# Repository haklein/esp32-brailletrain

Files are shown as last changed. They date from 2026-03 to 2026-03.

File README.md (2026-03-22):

# ESP32-S3 Braille Trainer

A braille training device that connects an ESP32-S3 to a HandyTech BrailleWave 40-cell display via MAX232 level shifter. Includes a web UI for settings and monitoring, BLE HID pass-through for screen reader use, and maintenance tools.

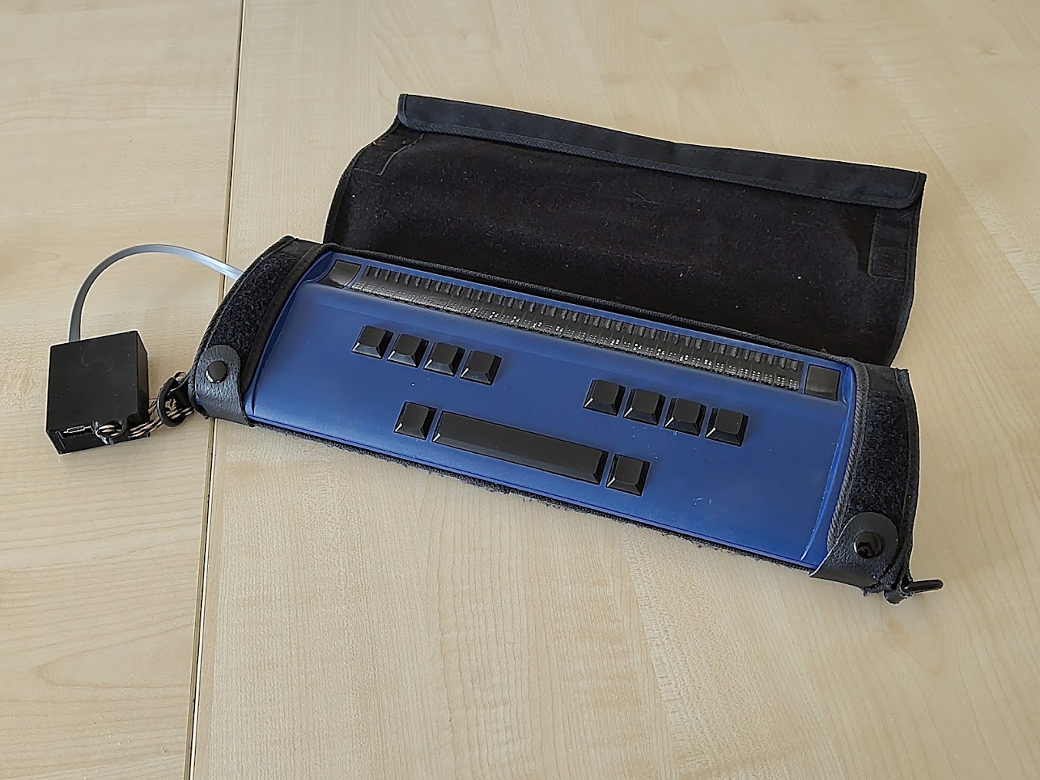
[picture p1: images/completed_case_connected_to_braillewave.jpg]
3D-printed adapter case with RJ-12 cable plugged into a blue HandyTech BrailleWave 40-cell braille display in its carry pouch


## Hardware

- Seeed Studio XIAO ESP32-S3 (or ESP32-S3-DevKitC-1)
- HandyTech BrailleWave (40 cells, HT serial protocol)
- MAX232 level shifter (TTL ↔ RS-232)
- 14500 Li-Ion battery (3.7V 1000mAh)

```
XIAO:      D1/A1 (GPIO2, TX) → MAX232 → RJ-12 → BrailleWave
           D2/A2 (GPIO3, RX) ← MAX232 ← RJ-12 ← BrailleWave

DevKitC-1: GPIO 7 (TX) → MAX232 → RJ-12 → BrailleWave
           GPIO 6 (RX) ← MAX232 ← RJ-12 ← BrailleWave
```

| | |
|---|---|
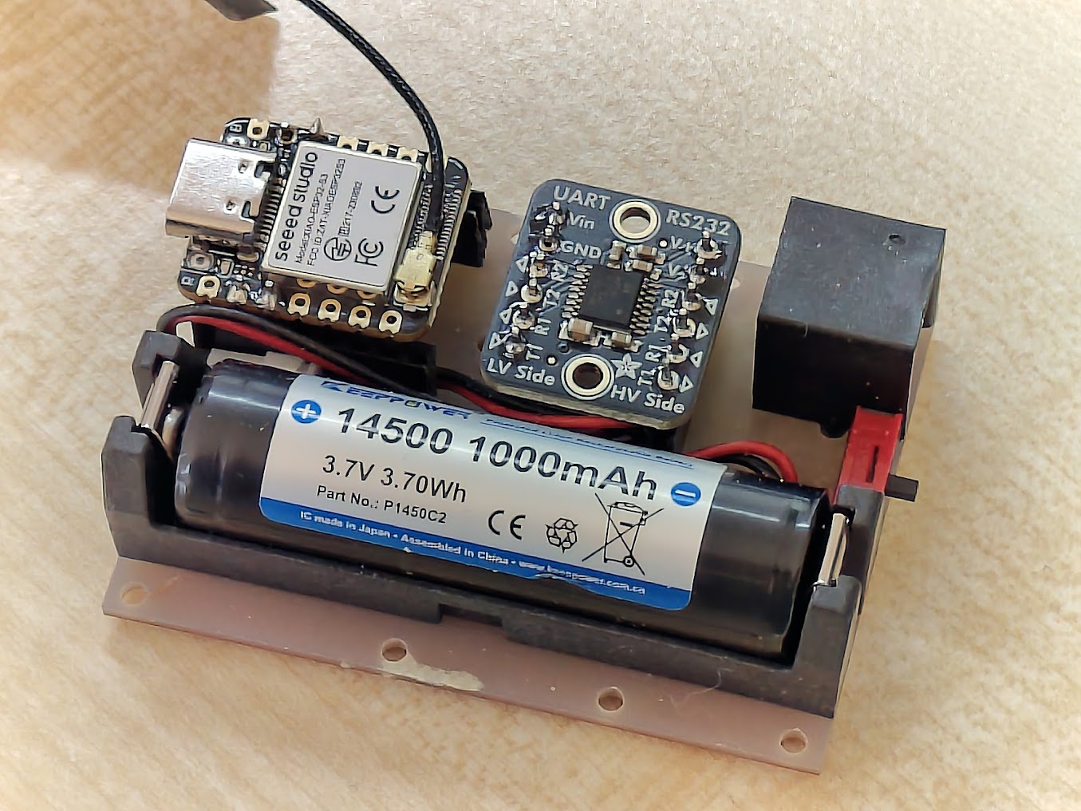
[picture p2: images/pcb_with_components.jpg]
Custom PCB with Seeed XIAO ESP32-S3 module, MAX232 level shifter, and 14500 Li-Ion battery in holder, viewed from above
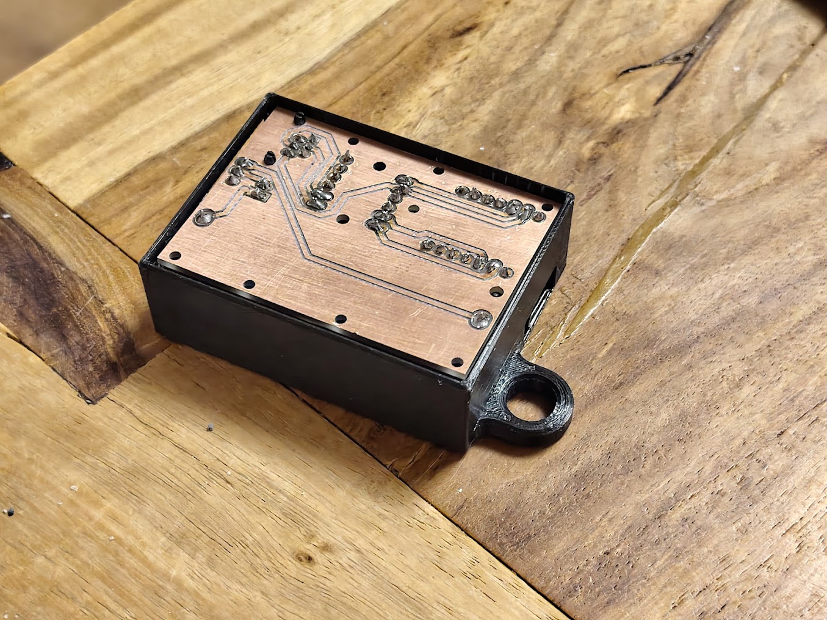
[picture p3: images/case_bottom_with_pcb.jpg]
Bottom of 3D-printed case showing milled copper PCB with through-hole solder joints and RJ-12 cable exit
|  |  |
| XIAO ESP32-S3, MAX232, 14500 battery holder | Custom PCB in 3D-printed case with RJ-12 connector |

### Bill of Materials

| Component | Description | Link |
|---|---|---|
| Seeed Studio XIAO ESP32-S3 | Microcontroller with WiFi + BLE | [Seeed Wiki](https://wiki.seeedstudio.com/xiao_esp32s3_getting_started/) |
| Adafruit RS232 Pal | MAX3232E dual-channel UART to RS-232 level shifter | [Adafruit 5987](https://www.adafruit.com/product/5987) |
| Keystone 1028 | 14500 / AA battery holder | |
| MSK12D18G2 | SPDT slide switch, 3-pin, 2.54mm pitch (or any compatible) | |
| RJ-12 socket | 6P6C through-hole, for direct connection to BrailleWave | |
| 14500 Li-Ion battery | 3.7V 1000mAh (AA-size lithium) | |

### Schematic

<a href="pcb/Schematic_esp32-brailletrain_2026-03-22.svg">Circuit schematic showing XIAO ESP32-S3 connected to MAX3232E level shifter, RJ-12 connector for BrailleWave, 14500 battery with slide switch, and status LED</a>

### PCB

Gerber files and a DXF for CNC milling are in the `pcb/` directory. The PCB was designed as a single-layer board, CNC milled with only the bottom side island-routed (see the included DXF).

**Note:** One screw hole collides with the 5V SMD pad on the XIAO ESP32-S3. This was not fixed since it doesn't matter for the milled version (no top copper). If you plan to send the Gerber to a PCB manufacturer, be aware of this overlap — you'll likely want to leave the top copper layer empty or remove that pad from the design.

## Features

### Training
- Letter, word, and mixed training modes
- 26-level progressive curriculum (teaching order: e, a, i, o, s, h, b, c, ...)
- Oxford 5000 word list with frequency weights, filtered by introduced letters
- Per-letter statistics, confusion tracking, streak counting
- Auto-advancement when accuracy thresholds are met
- Confusable pair drills (d/f, e/i, h/j, m/n, etc.) plus actual confusion-based selection
- Per-letter confusion tracking across both letter and word modes (e.g., bed→beg records d/g confusion)
- Mirror mode (right-hand) and wide word spacing options
- Ergonomic positioning: left word at cell 12, mirror at cell 24, 4-cell gap
- Configurable max word length
- All settings persisted across reboots

### Web UI

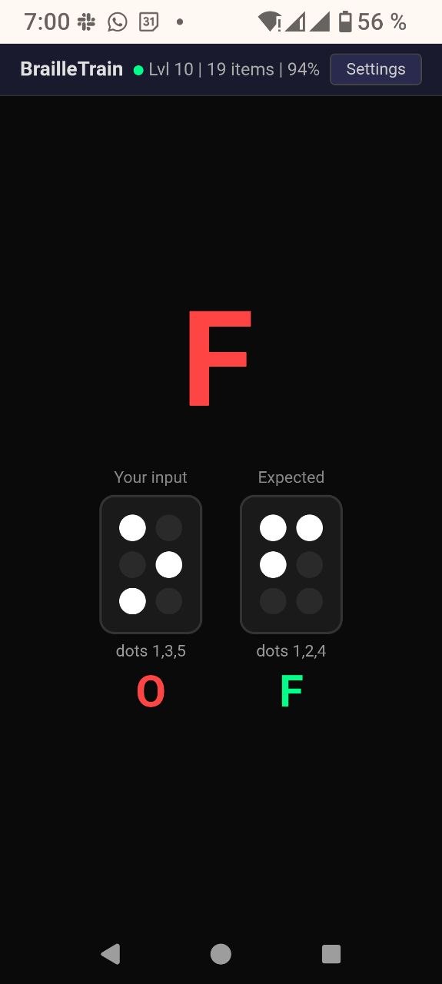
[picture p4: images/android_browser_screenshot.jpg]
Android browser showing BrailleTrain web UI after an incorrect answer: prompted letter F, user typed O, with dot pattern comparison showing dots 1,3,5 versus expected dots 1,2,4


- Real-time WebSocket updates at `http://brailletrain.local`
- Does not reveal the prompted letter/word — only shows result after input
- Level selector, mode switcher, option toggles
- Screen wake lock during training (releases after 5 min inactivity)
- Optional sound feedback: chime on correct, buzz on error (Web Audio API, no samples)
- Statistics panel: per-letter accuracy table, top confusion pairs, overall stats
- Reset option to clear all statistics and settings (e.g., for user change)
- BrailleWave connection status indicator with auto-reconnect

### WiFi
- Always runs AP mode (SSID: `BrailleTrain`, open)
- Optional STA mode — scan and connect to existing networks from the web UI
- Credentials saved to flash, auto-reconnects on boot
- mDNS: `http://brailletrain.local`

### BLE HID Braille Display (Dual Protocol)
- Advertises as "BrailleWave 40" (BLE HID, appearance 0x03C9)
- When a screen reader connects via BLE, the device enters pass-through mode
- Host cell data → ESP32 → UART → BrailleWave display
- BrailleWave keys → UART → ESP32 → HID input reports → Host
- Auto-reverts to trainer mode on BLE disconnect
- **Dual protocol support** — both served simultaneously on one BLE HID service:
  - **Standard HID Braille** (Usage Page 0x41, reports 0x11/0x12/0x13): for iOS VoiceOver, Android TalkBack, and other standard HID Braille consumers
  - **HandyTech USB-HID** (Vendor reports 0x01/0x02/0xFB/0xFC): serial tunnel for brltty's `ht` driver — wraps HT UART frames in HID reports
- PnP ID: HandyTech vendor 0x1FE4, product 0x0003 (USB-HID adapter)

#### brltty on Linux (Fedora/GNOME)

brltty's `ht` driver uses USB-specific HID APIs, so BLE HID requires a bridge.
`braille-bridge.py` translates between the ESP32's HT vendor HID reports and a
PTY that brltty reads as a serial device.

```bash
# Build the tcsetattr shim (one-time, needed because PTYs don't support parity)
gcc -shared -fPIC -o /tmp/pty_serial_shim.so - -ldl <<'EOF'
#define _GNU_SOURCE
#include <dlfcn.h>
#include <termios.h>
#include <unistd.h>
#include <errno.h>
typedef int (*fn)(int, int, const struct termios *);
int tcsetattr(int fd, int a, const struct termios *t) {
    static fn real = 0;
    if (!real) real = (fn)dlsym(RTLD_NEXT, "tcsetattr");
    int r = real(fd, a, t);
    if (r == -1 && errno == EINVAL && isatty(fd)) { errno = 0; return 0; }
    return r;
}
EOF

# Start bridge (auto-detects hidraw device)
sudo python3 braille-bridge.py &

# Start brltty
sudo LD_PRELOAD=/tmp/pty_serial_shim.so brltty -b ht -d /tmp/braillewave -n &

# Start Orca for GUI braille output
orca --replace &
```

### Status LED
- Flashes during BrailleWave connection attempts (yellow on DevKitC-1, white on XIAO)
- Solid on when connected (green on DevKitC-1, white on XIAO)
- Off when disconnected

### Maintenance
- **Exercise mode**: flips all dots on/off at slow (1s) or fast (200ms) intervals for 5 or 15 minutes — for pin break-in and cleaning
- **Test mode**: cycles through every dot on every cell sequentially; reports all key presses/releases in the web UI
- **Auto-reconnect**: detects BrailleWave sleep/power-off after 30s inactivity, reconnects within 3s of power-on (uses HT ping when supported, falls back to reset)
- Manual reconnect button
- **Device probe**: queries serial number, firmware version, cell count, RTC, firmness, ping support via HT extended protocol
- **RTC sync**: synchronize BrailleWave clock from ESP32 (requires NTP via WiFi STA)
- **Firmness control**: adjust pin pressure (soft/medium/hard) on supported models

## Building

Requires [PlatformIO](https://platformio.org/).

```bash
pio run              # build
pio run -t upload    # flash
```

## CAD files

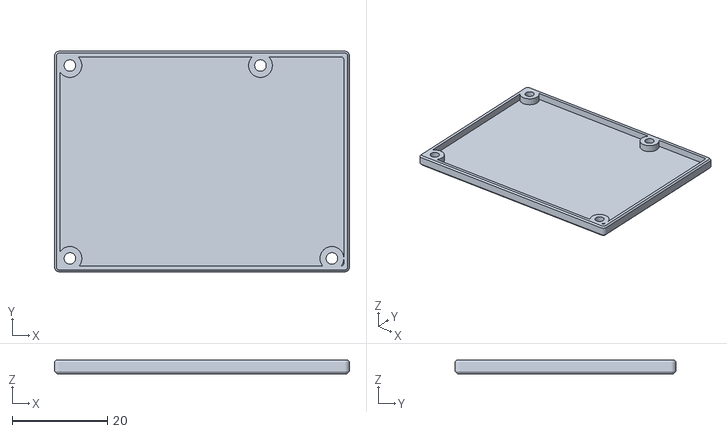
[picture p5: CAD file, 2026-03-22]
cad/brailletrain-case-lid.stl
61.9 x 46.3 x 3.00

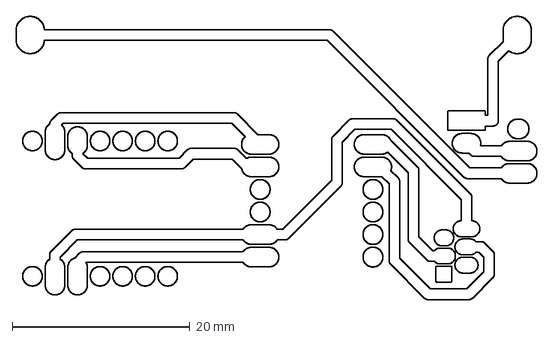
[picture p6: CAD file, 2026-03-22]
pcb/Gerber_BottomLayer.GBL_iso.DXF
58.7 x 31.9 mm

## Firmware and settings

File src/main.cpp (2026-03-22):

/*
 * ESP32-S3 Braille Trainer with web UI
 *
 * Hardware:
 *   BRL_TX -> MAX232 RX pin -> DB9 -> BrailleWave
 *   BRL_RX <- MAX232 TX pin <- DB9 <- BrailleWave
 *   USB CDC -> PC serial monitor at 115200
 *   Pin assignments per board in platformio.ini
 *
 * WiFi AP "BrailleTrain" -> http://192.168.4.1
 */

#include <Arduino.h>
#include <WiFi.h>
#include <ESPmDNS.h>
#include <ArduinoOTA.h>
#include <LittleFS.h>
#include <ESPAsyncWebServer.h>
#include <ArduinoJson.h>

#include "braille_data.h"
#include "progress.h"
#include "engine.h"
#include "wordlist.h"
#include "html_content.h"
#include "ble_braille.h"

// =========================================================================
// Hardware
// =========================================================================

#define DBG Serial  // USB CDC on ESP32-S3

// BRL_TX and BRL_RX defined via build flags in platformio.ini
HardwareSerial BRL(1);

// Status LED (optional, per-board via platformio.ini)
//   LED_PIN  = simple GPIO LED (active low, XIAO)
//   LED_RGB  = addressable WS2812 (DevKitC-1, GPIO48)
#if defined(LED_RGB)
static inline void led_on()      { neopixelWrite(LED_RGB, 0, 20, 0); }  // green
static inline void led_attempt() { neopixelWrite(LED_RGB, 20, 12, 0); } // yellow
static inline void led_off()     { neopixelWrite(LED_RGB, 0, 0, 0); }
#elif defined(LED_PIN)
static inline void led_on()      { digitalWrite(LED_PIN, LOW); }  // active low
static inline void led_attempt() { digitalWrite(LED_PIN, LOW); }
static inline void led_off()     { digitalWrite(LED_PIN, HIGH); }
#else
static inline void led_on()      {}
static inline void led_attempt() {}
static inline void led_off()     {}
#endif

#define HT_PKT_RESET    0xFF
#define HT_PKT_OK       0xFE
#define HT_PKT_BRAILLE  0x01
#define HT_PKT_EXTENDED 0x79
#define HT_MODEL_WAVE   0x05
#define HT_SYN          0x16

// Extended packet types
#define HT_EXT_BRAILLE          0x01
#define HT_EXT_KEY              0x04
#define HT_EXT_CONFIRMATION     0x07
#define HT_EXT_PING             0x19
#define HT_EXT_GET_SERIAL       0x41
#define HT_EXT_SET_RTC          0x44
#define HT_EXT_GET_RTC          0x45
#define HT_EXT_SET_FIRMNESS     0x60
#define HT_EXT_GET_FIRMNESS     0x61
#define HT_EXT_GET_PROTO_PROPS  0xC1
#define HT_EXT_GET_FW_VERSION   0xC2

// =========================================================================
// Web server
// =========================================================================

AsyncWebServer server(80);
AsyncWebSocket ws("/ws");

// =========================================================================
// Settings (changed via web or defaults)
// =========================================================================

static volatile bool mirror_enabled = false;
static volatile bool word_spacing = false;
static volatile bool keepalive_enabled = true;
static volatile bool ergonomic_enabled = false;
static volatile int max_word_len = 0;  // 0 = unlimited

enum TrainMode { MODE_LETTERS, MODE_WORDS, MODE_MIXED };
static volatile int training_mode = MODE_LETTERS;

// BrailleWave connectivity
static bool brl_connected = false;
static unsigned long last_key_time = 0;
static unsigned long last_keepalive = 0;
static volatile bool pending_reconnect = false;

// Pending settings from WebSocket (processed in main loop)
static volatile int pending_level = -1;

// Pending WiFi commands from WebSocket
static volatile bool pending_wifi_scan = false;
static volatile bool pending_wifi_connect = false;
static volatile bool pending_wifi_disconnect = false;
static char pending_ssid[33] = {0};
static char pending_pass[65] = {0};

// =========================================================================
// Key codes
// =========================================================================

struct KeyInfo { uint8_t code; int dot; };

static const KeyInfo KEY_TABLE[] = {
    {0x03, 7}, {0x07, 3}, {0x0B, 2}, {0x0F, 1},
    {0x13, 4}, {0x17, 5}, {0x1B, 6}, {0x1F, 8},
    {0x10, -1},  // space
    {0x0C, -2},  // nav left
    {0x14, -3},  // nav right
    {0x08, -4},  // nav prev
    {0x04, -5},  // nav next
};
#define KEY_TABLE_SIZE (sizeof(KEY_TABLE) / sizeof(KEY_TABLE[0]))

#define DOT_KEY(ki)  ((ki).dot > 0)
#define NAV_LEFT   0x0C
#define NAV_RIGHT  0x14
#define NAV_PREV   0x08
#define NAV_NEXT   0x04
#define KEY_SPACE  0x10

// =========================================================================
// HT protocol
// =========================================================================

static bool ht_reset() {
    DBG.println("HT reset...");
    led_attempt();
    while (BRL.available()) BRL.read();
    BRL.write((uint8_t)HT_PKT_RESET);
    BRL.flush();
    delay(300);

    uint8_t buf[16];
    int count = 0;
    unsigned long deadline = millis() + 1000;
    while (millis() < deadline && count < 16)
        if (BRL.available()) buf[count++] = BRL.read();

    for (int i = 0; i < count; i++)
        if (buf[i] == HT_PKT_OK) {
            DBG.println("  BrailleWave OK");
            led_on();  // stay solid
            return true;
        }
    led_off();
    return false;
}

static void ht_write_cells(const uint8_t *cells) {
    BRL.write((uint8_t)HT_PKT_BRAILLE);
    BRL.write(cells, HT_CELLS);
    BRL.flush();
    delay(50);
    while (BRL.available()) BRL.read();
}

static void ht_clear() {
    uint8_t cells[HT_CELLS] = {0};
    ht_write_cells(cells);
}

// Send an extended packet: type + optional data
static void ht_send_ext(uint8_t type, const uint8_t *data = nullptr, int data_len = 0) {
    BRL.write((uint8_t)HT_PKT_EXTENDED);
    BRL.write((uint8_t)HT_MODEL_WAVE);
    BRL.write((uint8_t)(data_len + 1));  // length includes type byte
    BRL.write(type);
    if (data && data_len > 0) BRL.write(data, data_len);
    BRL.write((uint8_t)HT_SYN);
    BRL.flush();
}

// Read an extended packet response. Returns payload length (0 = no response).
// out_type gets the response type, out_data gets payload (up to out_max bytes).
static int ht_recv_ext(uint8_t *out_type, uint8_t *out_data, int out_max,
                       int timeout_ms = 500) {
    unsigned long deadline = millis() + timeout_ms;
    // Look for 0x79 header
    while (millis() < deadline) {
        if (!BRL.available()) { delay(1); continue; }
        int b = BRL.read();
        if (b != HT_PKT_EXTENDED) continue;

        // Read model, length, type
        while (BRL.available() < 3 && millis() < deadline) delay(1);
        if (BRL.available() < 3) return 0;
        uint8_t model = BRL.read();
        uint8_t len = BRL.read();     // includes type byte
        *out_type = BRL.read();
        int payload_len = len - 1;

        // Read payload + SYN
        int got = 0;
        while (got < payload_len && millis() < deadline) {
            if (BRL.available()) {
                uint8_t c = BRL.read();
                if (got < out_max) out_data[got] = c;
                got++;
            } else delay(1);
        }
        // Read trailing SYN
        while (millis() < deadline) {
            if (BRL.available()) { BRL.read(); break; }
            delay(1);
        }
        return min(got, out_max);
    }
    return 0;
}

// Ping — less disruptive than full reset for keepalive
static bool ht_ping() {
    while (BRL.available()) BRL.read();
    ht_send_ext(HT_EXT_PING);
    // Accept any response (extended confirmation, or even just bytes back)
    unsigned long deadline = millis() + 300;
    while (millis() < deadline) {
        if (BRL.available()) {
            while (BRL.available()) BRL.read();
            return true;
        }
        delay(5);
    }
    return false;
}

// Probe device: try all extended queries, return results as JSON
static void ht_probe(String &out) {
    JsonDocument doc;
    doc["t"] = "devinfo";
    uint8_t rtype, rbuf[64];
    int rlen;

    // Serial number
    while (BRL.available()) BRL.read();
    ht_send_ext(HT_EXT_GET_SERIAL);
    rlen = ht_recv_ext(&rtype, rbuf, sizeof(rbuf));
    if (rlen > 0) {
        rbuf[min(rlen, 63)] = 0;
        doc["serial"] = (const char *)rbuf;
        DBG.printf("HT serial: %s\n", rbuf);
    }

    // Firmware version
    while (BRL.available()) BRL.read();
    ht_send_ext(HT_EXT_GET_FW_VERSION);
    rlen = ht_recv_ext(&rtype, rbuf, sizeof(rbuf));
    if (rlen > 0) {
        rbuf[min(rlen, 63)] = 0;
        doc["firmware"] = (const char *)rbuf;
        DBG.printf("HT firmware: %s\n", rbuf);
    }

    // Protocol properties (cell count)
    while (BRL.available()) BRL.read();
    ht_send_ext(HT_EXT_GET_PROTO_PROPS);
    rlen = ht_recv_ext(&rtype, rbuf, sizeof(rbuf));
    if (rlen > 0) {
        doc["cells"] = (int)rbuf[0];
        DBG.printf("HT cells: %d\n", rbuf[0]);
    }

    // Firmness
    while (BRL.available()) BRL.read();
    ht_send_ext(HT_EXT_GET_FIRMNESS);
    rlen = ht_recv_ext(&rtype, rbuf, sizeof(rbuf));
    if (rlen > 0) {
        doc["firmness"] = (int)rbuf[0];
        doc["has_firmness"] = true;
        DBG.printf("HT firmness: %d\n", rbuf[0]);
    }

    // RTC
    while (BRL.available()) BRL.read();
    ht_send_ext(HT_EXT_GET_RTC);
    rlen = ht_recv_ext(&rtype, rbuf, sizeof(rbuf));
    if (rlen >= 7) {
        int year = (rbuf[0] << 8) | rbuf[1];
        char ts[32];
        snprintf(ts, sizeof(ts), "%04d-%02d-%02d %02d:%02d:%02d",
                 year, rbuf[2], rbuf[3], rbuf[4], rbuf[5], rbuf[6]);
        doc["rtc"] = ts;
        doc["has_rtc"] = true;
        DBG.printf("HT RTC: %s\n", ts);
    }

    // Ping
    bool ping_ok = ht_ping();
    doc["ping"] = ping_ok;

    serializeJson(doc, out);
}

// =========================================================================
// Display helpers (mirror + spacing)
// =========================================================================

static void display_cells(const uint8_t *src, int src_len) {
    uint8_t cells[HT_CELLS] = {0};

    int left = ergonomic_enabled ? 12 : 0;

    if (mirror_enabled) {
        // Right (mirror) copy: prefer cell 24, push left only if it won't fit
        int right = 24;
        if (right + src_len > HT_CELLS)
            right = HT_CELLS - src_len;
        if (right < 0) right = 0;

        // Left copy: push left if 4-cell gap can't be maintained
        if (left + src_len + 4 > right)
            left = right - src_len - 4;
        if (left < 0) left = 0;

        for (int i = 0; i < src_len && right + i < HT_CELLS; i++)
            cells[right + i] = src[i];
    } else {
        // No mirror: ensure it fits
        if (left + src_len > HT_CELLS)
            left = HT_CELLS - src_len;
        if (left < 0) left = 0;
    }

    for (int i = 0; i < src_len && left + i < HT_CELLS; i++)
        cells[left + i] = src[i];

    ht_write_cells(cells);
}

static void display_letter(char letter) {
    uint8_t c[1] = { char_to_cell(letter) };
    display_cells(c, 1);
}

static int word_to_cells(const char *word, uint8_t *out, int max_cells) {
    int pos = 0;
    for (int i = 0; word[i] && pos < max_cells; i++) {
        if (i > 0 && word_spacing) {
            if (pos < max_cells) out[pos++] = 0x00;
        }
        if (pos < max_cells) out[pos++] = char_to_cell(word[i]);
    }
    return pos;
}

static void display_word(const char *word) {
    uint8_t cells[HT_CELLS] = {0};
    int n = word_to_cells(word, cells, mirror_enabled ? HT_CELLS / 2 : HT_CELLS);
    display_cells(cells, n);
}

static void display_comparison(uint8_t got_cell, uint8_t exp_cell) {
    uint8_t cells[4] = { got_cell, 0, exp_cell, 0 };
    display_cells(cells, 4);
}

static void display_word_progress(const char *typed, int typed_len) {
    uint8_t cells[HT_CELLS] = {0};
    int pos = 0;
    for (int i = 0; i < typed_len; i++) {
        if (i > 0 && word_spacing) {
            if (pos < HT_CELLS) cells[pos++] = 0x00;
        }
        if (pos < HT_CELLS) cells[pos++] = char_to_cell(typed[i]);
    }
    display_cells(cells, pos);
}

// =========================================================================
// Chord accumulator
// =========================================================================

static uint8_t pressed_keys[16];
static int pressed_n = 0;
static uint8_t chord_keys[16];
static int chord_n = 0;

static bool chord_ready = false;
static uint8_t chord_dots = 0;
static bool chord_is_space = false;
static uint8_t chord_nav = 0;
static int routing_key = -1;

static const KeyInfo *lookup_key(uint8_t code) {
    for (int i = 0; i < (int)KEY_TABLE_SIZE; i++)
        if (KEY_TABLE[i].code == code) return &KEY_TABLE[i];
    return NULL;
}

static void finish_chord() {
    if (chord_n == 0) return;
    chord_dots = 0;
    chord_is_space = false;
    chord_nav = 0;

    for (int i = 0; i < chord_n; i++) {
        const KeyInfo *ki = lookup_key(chord_keys[i]);
        if (ki) {
            if (ki->dot > 0) chord_dots |= (1 << (ki->dot - 1));
            else if (chord_keys[i] == KEY_SPACE) chord_is_space = true;
            else chord_nav = chord_keys[i];
        }
    }
    chord_ready = true;
    chord_n = 0;
}

static void drain_ext_packet() {
    // Consume model + len, then len bytes + trailing SYN
    unsigned long deadline = millis() + 100;
    while (BRL.available() < 2 && millis() < deadline) delay(1);
    if (BRL.available() < 2) return;
    BRL.read();                         // model
    uint8_t len = BRL.read();           // length (includes type)
    int remain = len + 1;               // data + SYN
    while (remain > 0 && millis() < deadline) {
        if (BRL.available()) { BRL.read(); remain--; }
        else delay(1);
    }
}
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
void loop() {
    ArduinoOTA.handle();

    // BLE HID mode switching
    if (bleHID.connected() && app_mode == AppMode::TRAINER) {
        app_mode = AppMode::PASSTHROUGH;
        DBG.println("\n=== BLE host connected — pass-through mode ===");
        chord_reset();
        passthrough_reset_keys();
        ws_send("{\"t\":\"ble\",\"s\":\"connected\"}");
    } else if (!bleHID.connected() && app_mode == AppMode::PASSTHROUGH) {
        app_mode = AppMode::TRAINER;
        DBG.println("\n=== BLE host disconnected — trainer mode ===");
        state = State::RESET;
        ws_send("{\"t\":\"ble\",\"s\":\"disconnected\"}");
    }


    // Periodic WebSocket cleanup + heartbeat
    ws.cleanupClients();
    {
        static unsigned long last_hb = 0;
        if (millis() - last_hb > 5000) {
            last_hb = millis();
            ws_send("{\"t\":\"hb\"}");
        }
    }

    // Process pending WiFi commands
    if (pending_wifi_scan) {
        pending_wifi_scan = false;
        int n = WiFi.scanNetworks();
        JsonDocument doc;
        doc["t"] = "wscanr";
        JsonArray nets = doc["nets"].to<JsonArray>();
        for (int i = 0; i < n && i < 20; i++) {
            JsonObject net = nets.add<JsonObject>();
            net["s"] = WiFi.SSID(i);
            net["r"] = WiFi.RSSI(i);
            net["e"] = WiFi.encryptionType(i) != WIFI_AUTH_OPEN;
        }
        String out;
        serializeJson(doc, out);
        ws_send(out.c_str());
        WiFi.scanDelete();
    }

    if (pending_wifi_connect) {
        pending_wifi_connect = false;
        strlcpy(wifi_ssid, pending_ssid, sizeof(wifi_ssid));
        strlcpy(wifi_pass, pending_pass, sizeof(wifi_pass));
        wifi_save_creds();
        WiFi.disconnect(false);
        delay(100);
        WiFi.begin(wifi_ssid, wifi_pass);
        unsigned long t0 = millis();
        while (WiFi.status() != WL_CONNECTED && millis() - t0 < 10000)
            delay(100);
        if (WiFi.status() == WL_CONNECTED) {
            DBG.printf("WiFi STA: %s  IP: %s\n", wifi_ssid,
                       WiFi.localIP().toString().c_str());
            wifi_freeze_dhcp();
        } else
            DBG.printf("WiFi STA: %s failed\n", wifi_ssid);
        ws_notify_wifi_status();
    }

    if (pending_wifi_disconnect) {
        pending_wifi_disconnect = false;
        WiFi.disconnect(false);
        wifi_ssid[0] = 0;
        wifi_pass[0] = 0;
        wifi_save_creds();
        DBG.println("WiFi STA disconnected");
        ws_notify_wifi_status();
    }

    // Manual reconnect request
    if (pending_reconnect) {
        pending_reconnect = false;
        DBG.println("Reconnect requested");
        if (ht_reset()) {
            delay(500);
            while (BRL.available()) BRL.read();
            brl_connected = true;
            last_key_time = millis();
            chord_reset();
            state = State::SHOW_ITEM;
            if (app_mode != AppMode::TRAINER) app_mode = AppMode::TRAINER;
            ws_send("{\"t\":\"brl\",\"s\":true}");
            DBG.println("BrailleWave reconnected");
        } else {
            brl_connected = false;
            ws_send("{\"t\":\"brl\",\"s\":false}");
            DBG.println("BrailleWave not responding");
        }
    }

    // Background keepalive: ping BrailleWave after inactivity
    if (keepalive_enabled && app_mode == AppMode::TRAINER
        && state != State::RESET) {
        unsigned long now = millis();
        if (brl_connected) {
            // Check if still alive after 30s of no keys
            if (now - last_key_time > 30000 && now - last_keepalive > 10000) {
                last_keepalive = now;
                if (!ht_reset()) {
                    brl_connected = false;
                    led_off();
                    ws_send("{\"t\":\"brl\",\"s\":false}");
                    DBG.println("BrailleWave: lost connection");
                } else {
                    // Still connected, redisplay current item
                    if (state == State::WAIT_INPUT) {
                        if (item_is_word) display_word(current_item);
                        else display_letter(current_item[0]);
                    }
                }
            }
        } else {
            // Disconnected — try reconnect every 3 seconds
            if (now - last_keepalive > 3000) {
                last_keepalive = now;
                if (ht_reset()) {
                    delay(500);
                    while (BRL.available()) BRL.read();
                    brl_connected = true;
                    last_key_time = millis();
                    chord_reset();
                    state = State::SHOW_ITEM;
                    ws_send("{\"t\":\"brl\",\"s\":true}");
                    DBG.println("BrailleWave: reconnected");
                }
            }
        }
    }

    // Always process HT USB-HID reports (brltty may send via report 0x02
    // even when we're not in passthrough mode)
    if (bleHID.connected()) {
        // Forward HT serial data from brltty → UART
        uint8_t ht_data[HT_HID_DATA_SIZE];
        uint8_t ht_len = 0;
        if (bleHID.processHtData(ht_data, &ht_len)) {
            BRL.write(ht_data, ht_len);
            BRL.flush();
            DBG.printf("HT-HID: forwarded %d bytes to UART\n", ht_len);
        }
        // Forward HT firmware commands
        uint8_t cmd = 0;
        if (bleHID.processHtCommand(&cmd)) {
            if (cmd == 0x01) {
                ht_uart_rx_len = 0;
                while (BRL.available()) BRL.read();
                DBG.println("HT-HID: flush buffers");
            }
        }
        // Buffer any UART responses for brltty GET_REPORT(0x01)
        // (only when NOT in full passthrough, which handles this itself)
        if (app_mode != AppMode::PASSTHROUGH) {
            bool got_data = false;
            while (BRL.available()) {
                bleHID.htBufferUartByte(BRL.read());
                got_data = true;
            }
            if (got_data)
                bleHID.htNotifyData();
        }
    }

    switch (app_mode) {
    case AppMode::PASSTHROUGH: passthrough_loop(); break;
    case AppMode::EXERCISE:    exercise_loop(); break;
    case AppMode::TESTMODE:    testmode_loop(); break;
    default:                   trainer_loop(); break;
    }
}

// =========================================================================
// Pass-through mode: bridge BLE HID ↔ BrailleWave UART
// =========================================================================

static void passthrough_loop() {
    uint8_t cells[HT_CELLS];
    if (bleHID.processPendingCells(cells))
        ht_write_cells(cells);
    passthrough_poll(bleHID);
}


// =========================================================================
// Exercise mode: flip all dots on/off for pin break-in / cleaning
// =========================================================================

static void exercise_loop() {
    unsigned long now = millis();
    if (now >= exercise_end) {
        ht_clear();
        app_mode = AppMode::TRAINER;
        state = State::RESET;
        ws_send("{\"t\":\"exdone\"}");
        DBG.println("Exercise done");
        return;
    }

    if (now - exercise_toggle >= exercise_interval) {
        exercise_toggle = now;
        exercise_on = !exercise_on;
        uint8_t cells[HT_CELLS];
        memset(cells, exercise_on ? 0xFF : 0x00, HT_CELLS);
        ht_write_cells(cells);

        // Report remaining time
        int secs_left = (exercise_end - now) / 1000;
        char buf[64];
        snprintf(buf, sizeof(buf), "{\"t\":\"extick\",\"s\":%d}", secs_left);
        ws_send(buf);
    }
}

// =========================================================================
// Test mode: cycle dots sequentially + report key presses
// =========================================================================
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

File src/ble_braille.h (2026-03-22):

/*
 * BLE HID Braille Display — dual-protocol bridge to HandyTech BrailleWave.
 *
 * Exposes TWO protocols on a single BLE HID service:
 *
 * 1) Standard HID Braille Display (Usage Page 0x41, reports 0x11-0x13)
 *    For iOS VoiceOver, Android TalkBack, and other standard consumers.
 *
 * 2) HandyTech USB-HID serial tunnel (reports 0x01, 0x02, 0xFB, 0xFC)
 *    For brltty's 'ht' driver. Wraps HT serial frames in HID reports.
 *
 * When a BLE host connects, the ESP32 bridges both simultaneously:
 *   Host cell data  → UART → BrailleWave
 *   BrailleWave keys → UART → Host HID input reports
 */
#pragma once

#include <BLEDevice.h>
#include <BLEServer.h>
#include <BLEHIDDevice.h>
#include <BLE2902.h>
#include "braille_data.h"

// ---------------------------------------------------------------------------
// Report IDs
// ---------------------------------------------------------------------------

// Standard HID Braille Display (Usage Page 0x41)
#define RPT_STD_KEYS     0x11   // Input:  2B dot/nav key bits
#define RPT_STD_ROUTER   0x12   // Input:  5B routing key bits
#define RPT_STD_CELLS    0x13   // Output: 40B cell data

// HandyTech USB-HID serial tunnel (for brltty ht driver)
#define RPT_HT_OUT_DATA  0x01   // Input (GET_REPORT): HT serial from device
#define RPT_HT_IN_DATA   0x02   // Output (SET_REPORT): HT serial to device
#define RPT_HT_IN_CMD    0xFB   // Output (SET_REPORT): firmware command
#define RPT_HT_OUT_VER   0xFC   // Input (GET_REPORT): firmware version

// HT USB-HID data report payload size (matches real HT USB-HID adapters)
// Format: [report_id] [length] [data...] padded to fixed size
#define HT_HID_DATA_SIZE 64

// ---------------------------------------------------------------------------
// HID Report Descriptor — dual protocol
// ---------------------------------------------------------------------------
//
// Collection 1: Standard HID Braille (Usage Page 0x41)
//   Input Report 0x11 (2 bytes): dot keys 1-8, space, nav buttons
//   Input Report 0x12 (5 bytes): 40 router keys (1 bit each)
//   Output Report 0x13 (40 bytes): braille cell data from host
//
// Collection 2: HandyTech USB-HID serial tunnel (Usage Page 0x01 Generic)
//   Input Report 0x01 (64 bytes): HT serial data from device
//   Output Report 0x02 (64 bytes): HT serial data to device
//   Output Report 0xFB (2 bytes): firmware command
//   Input Report 0xFC (3 bytes): firmware version

static const uint8_t BRL_REPORT_MAP[] = {
    // =================================================================
    // Collection 1: Standard HID Braille Display
    // =================================================================
    0x05, 0x41,             // Usage Page (Braille Display)
    0x09, 0x01,             // Usage (Braille Display)
    0xA1, 0x01,             // Collection (Application)

    // --- Input Report 0x11: braille keyboard + nav ---
    0x85, RPT_STD_KEYS,     //   Report ID (0x11)
    0x05, 0x41,             //   Usage Page (Braille Display)
    // Dots 1-8
    0x0A, 0x01, 0x02,       //   Usage (Braille Keyboard Dot 1)
    0x0A, 0x02, 0x02,       //   Usage (Braille Keyboard Dot 2)
    0x0A, 0x03, 0x02,       //   Usage (Braille Keyboard Dot 3)
    0x0A, 0x04, 0x02,       //   Usage (Braille Keyboard Dot 4)
    0x0A, 0x05, 0x02,       //   Usage (Braille Keyboard Dot 5)
    0x0A, 0x06, 0x02,       //   Usage (Braille Keyboard Dot 6)
    0x0A, 0x07, 0x02,       //   Usage (Braille Keyboard Dot 7)
    0x0A, 0x08, 0x02,       //   Usage (Braille Keyboard Dot 8)
    0x15, 0x00,             //   Logical Minimum (0)
    0x25, 0x01,             //   Logical Maximum (1)
    0x75, 0x01,             //   Report Size (1)
    0x95, 0x08,             //   Report Count (8)
    0x81, 0x02,             //   Input (Data, Var, Abs)
    // Space + nav (5 buttons) + 3 padding bits
    0x0A, 0x09, 0x02,       //   Usage (Braille Keyboard Space)
    0x0A, 0x0A, 0x02,       //   Usage (Braille Keyboard Left Space)
    0x0A, 0x0B, 0x02,       //   Usage (Braille Keyboard Right Space)
    0x0A, 0x13, 0x02,       //   Usage (Joystick Left)
    0x0A, 0x14, 0x02,       //   Usage (Joystick Right)
    0x95, 0x05,             //   Report Count (5)
    0x81, 0x02,             //   Input (Data, Var, Abs)
    // 3-bit padding
    0x95, 0x03,             //   Report Count (3)
    0x81, 0x03,             //   Input (Const)

    // --- Input Report 0x12: router keys ---
    0x85, RPT_STD_ROUTER,   //   Report ID (0x12)
    0x05, 0x41,             //   Usage Page (Braille Display)
    0x09, 0xFA,             //   Usage (Router Set 1)
    0xA1, 0x02,             //   Collection (Logical)
    0x0A, 0x00, 0x01,       //     Usage (Router Key)
    0x15, 0x00,             //     Logical Minimum (0)
    0x25, 0x01,             //     Logical Maximum (1)
    0x75, 0x01,             //     Report Size (1)
    0x95, 0x28,             //     Report Count (40)
    0x81, 0x02,             //     Input (Data, Var, Abs)
    0xC0,                   //   End Collection

    // --- Output Report 0x13: braille cells from host ---
    0x85, RPT_STD_CELLS,    //   Report ID (0x13)
    0x05, 0x41,             //   Usage Page (Braille Display)
    0x09, 0x02,             //   Usage (Braille Row)
    0xA1, 0x02,             //   Collection (Logical)
    0x09, 0x03,             //     Usage (8 Dot Braille Cell)
    0x15, 0x00,             //     Logical Minimum (0)
    0x26, 0xFF, 0x00,       //     Logical Maximum (255)
    0x75, 0x08,             //     Report Size (8)
    0x95, 0x28,             //     Report Count (40)
    0x91, 0x02,             //     Output (Data, Var, Abs)
    0xC0,                   //   End Collection

    0xC0,                   // End Collection (Standard Braille)

    // =================================================================
    // Collection 2: HandyTech USB-HID serial tunnel
    // =================================================================
    0x06, 0x00, 0xFF,       // Usage Page (Vendor Defined 0xFF00)
    0x09, 0x01,             // Usage (Vendor Usage 1)
    0xA1, 0x01,             // Collection (Application)

    // --- Report 0x01: HT serial data from device (brltty polls via GET_REPORT) ---
    0x85, RPT_HT_OUT_DATA,  //   Report ID (0x01)
    0x09, 0x01,             //   Usage (Vendor Data Out)
    0x15, 0x00,             //   Logical Minimum (0)
    0x26, 0xFF, 0x00,       //   Logical Maximum (255)
    0x75, 0x08,             //   Report Size (8)
    0x95, HT_HID_DATA_SIZE, //   Report Count (64)
    0x81, 0x02,             //   Input (Data, Var, Abs)
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

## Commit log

2026-03-13 ESP32-S3 standalone braille trainer for HT BrailleWave
    Ported from brailletrain Python app to ESP32 Arduino/PlatformIO.
    Talks to BrailleWave via MAX232 level shifter on GPIO 6/7 (19200 8O1).
    Features:
    - Weighted letter selection (error/recency/confusion/newest boost)
    - Auto-advancement with configurable thresholds
    - Contrast drills for confusable pairs
    - Teaching messages (dot 3 / dots 3,6 structural patterns)
    - Progress persistence to LittleFS flash (JSON)
    - Routing keys (0-39) for direct level selection
    - Chord input with accumulation, nav key controls
    [main.cpp]
2026-03-13 Add web UI, word training, mirror, and wide spacing
    - WiFi AP "BrailleTrain" with async web server + WebSocket
    - Real-time browser display: huge letter/word, braille dot comparison on error
    - Settings panel: level, mode (letters/words/mixed), mirror, word spacing
    - Mirror option duplicates cells to right half for right-hand reading
    - Word spacing inserts blank cell between characters
    - Word training mode with chord-per-letter input
    - Weighted word selection by letter weakness
    - Per-character word scoring with position feedback
    - Embedded ~700 word list (2-8 letters), filtered by level
    [main.cpp]
2026-03-14 Add BLE HID pass-through, WiFi client, no-reveal, exercise/test modes
    - BLE HID braille display (BrailleWave 40): auto pass-through when
    screen reader connects, reverts to trainer on disconnect
    - WiFi STA mode with web-based network scanner, saved credentials
    - mDNS announcement (brailletrain.local)
    - Web UI no longer reveals prompted letter/word until after input
    - Oxford 5000 word list replaces hand-curated 1500-word list
    - Exercise mode: all-dots on/off at slow/fast intervals for maintenance
    - Test mode: sequential dot cycling with live key reporting in web UI
    - Auto-reconnect to BrailleWave after sleep/power cycle
    - Screen wake lock during active training
    - Settings persistence (mode,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
    [ble_braille.h, main.cpp]
2026-03-14 Add heartbeat, auto-reload, sound feedback, update README
    - Server sends WebSocket heartbeat every 5s; client detects dead
    connections after 12s and forces reconnect
    - Page auto-reloads on reconnect to pull in latest firmware UI
    - Sound feedback option: Web Audio API chime/buzz (no samples)
    - README updated with ergonomic positioning, word length, sound
    [main.cpp]
2026-03-14 Switch debug serial to USB CDC, persist sound setting
    - Use USB CDC (Serial) instead of UART0 for debug output on ESP32-S3
    - Add ARDUINO_USB_CDC_ON_BOOT build flag
    - Change engine print_summary to accept Print& for compatibility
    - Persist sound feedback checkbox in localStorage
    - Add CLAUDE.md with README update rule
2026-03-14 Add statistics panel, confusion-based selection, HT extended protocol
    - Statistics UI: per-letter accuracy table (worst-first), top confusion
    pairs, overall stats; separate Stats button in header
    - Reset all option for user change
    - Engine uses actual confusion history to boost letter/word selection
    - Inter-word confusion already tracked per-character, now visible
    - HT extended protocol: probe device info (serial, firmware, cells,
    RTC, firmness, ping), set firmness, sync RTC
    - Keepalive tries ping before full reset on supported models
    - BrailleWave (0x05) confirmed basic-only, no extended support
    [main.cpp]
2026-03-15 Fix NVS crash, crash-resilient saves, wake lock cleanup
    - Freeze DHCP to static IP after connection to prevent NVS spinlock
    contention between DHCP renewal and BLE stack
    - Remove ht_ping() from keepalive — extended packets desync UART on
    BrailleWave (0x01 byte misinterpreted as cell write command)
    - Resync UART with ht_reset() after device probe
    - Add try-catch around WS message handler to prevent single errors
    from killing all message processing
    - Fix sound: init AudioContext on first user gesture via event listener
    - Crash-resilient progress saves (write tmp, rename)
    - Remove copyright notice from word list (own contribution)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
    [main.cpp]
2026-03-17 Add XIAO ESP32-S3 board support, status LED, OTA updates
    Support both Seeed Studio XIAO ESP32-S3 and ESP32-S3-DevKitC-1 with
    per-board pin assignments and LED types. Add ArduinoOTA for wireless
    flashing. Increase loop task stack to 16KB to fix WiFi scan crash.
    [main.cpp]
2026-03-18 Fix key parsing, add protocol-aware filtering, add test modes
    - Filter extended HT packets (0x79...) and ack bytes (0xFE 0x05) in
    poll_keys() to prevent phantom routing key triggers
    - Reject all unrecognized key codes, not just those >= 0x20
    - Add built-in loopback test (LOOPBACK_TEST) and HT protocol test
    (HT_PROTOCOL_TEST) modes via preprocessor defines with matching
    PlatformIO environments for both boards
    [main.cpp]
2026-03-22 Add dual-protocol BLE HID for brltty compatibility
    The ESP32 now serves both standard HID Braille (Usage Page 0x41,
    reports 0x11/0x12/0x13) and HandyTech USB-HID vendor reports
    (0x01/0x02/0xFB/0xFC) on a single BLE HID service. This allows
    brltty's ht driver to communicate via a Python bridge that translates
    between hidraw and a PTY serial device.
    - Renumber standard Braille reports to 0x11-0x13 (consumers match by
    usage page, not report ID)
    - Add vendor-defined HID collection with HT serial tunnel reports
    - Buffer UART bytes from BrailleWave for brltty GET_REPORT
    - Forward brltty SET_REPORT data to UART regardless of app mode
    - Fix PnP ID byte order (ESP32 BLE lib swaps 16-bit values)
    -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
    [ble_braille.h, main.cpp]
2026-03-22 Fix connector type: DB9 → RJ-12
2026-03-22 Add 3D-printable case CAD files (FreeCAD + STL)
    [brailletrain-case-lid.stl]
2026-03-22 Add PCB Gerber/DXF files, document screw hole vs 5V pad overlap
    [Gerber_BottomLayer.GBL_iso.DXF]
2026-03-22 Add bill of materials section
2026-03-22 Add schematic SVG with preview in README
